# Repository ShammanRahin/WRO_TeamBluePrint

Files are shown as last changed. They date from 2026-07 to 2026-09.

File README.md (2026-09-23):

# Team Blueprint — WRO Future Engineers 2026

<p align="center">
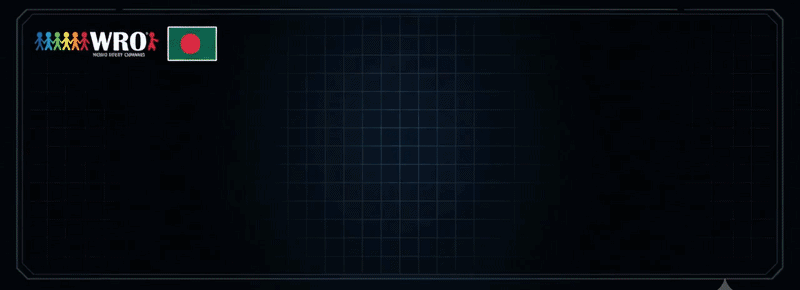
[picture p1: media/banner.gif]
Team Blueprint - WRO Future Engineers 2026
  
</p>

<div align="center">

### National Champions — WRO Bangladesh 2026, Future Engineers
### Heading to the WRO Open Championship Asia Pacific · Hyderabad, India · 25–27 September 2026








**[The Team](#1-the-team)** · **[The Vehicle](#3-the-vehicle)** · **[System Architecture](#4-system-architecture)** · **[How It Thinks](#5-how-the-car-thinks)** · **[Engineering Breakthroughs](#6-key-engineering-findings)** · **[Build & Calibrate](#7-build--fabrication)** · **[Troubleshooting](#9-field-troubleshooting)** · **[Sponsors](#15-sponsors--acknowledgements)**

</div>

---

## Knowledge Index & Deep-Dive Directory

> This repository is structured into an executive master overview below and dedicated technical deep-dive documents. If you want in-depth equations, calibration routines, or build instructions, use the index below:

| System Domain | Master Overview | Full Detailed Technical Guide | Primary Topics & Highlights |
|:---|:---|:---|:---|
| **Autonomous Logic** | [Section 5](#5-how-the-car-thinks) | **[docs/control_architecture.md](docs/control_architecture.md)** | State machines, lane-gap odometry correction, heading hold, 6-phase obstacle FSM, Pi perception |
| **Research & Findings** | [Section 6](#6-key-engineering-findings) | **[docs/engineering_findings.md](docs/engineering_findings.md)** | Optical slot collimators, mathematical parking failure proof, 3 steering geometries compared |
| **Mechanical & Build** | [Section 7](#7-build--fabrication) | **[docs/build_guide.md](docs/build_guide.md)** | 3D printing parameters, Dhaka-milled isolation PCBs, avionics wiring, step-by-step assembly |
| **Sensor Calibration** | [Section 8](#8-sensor-calibration) | **[docs/calibration.md](docs/calibration.md)** | 8-step empirical calibration protocol, regression math, slew limiters, master constants table |
| **Diagnostics & Pit Fixes** | [Section 9](#9-field-troubleshooting) | **[docs/troubleshooting.md](docs/troubleshooting.md)** | 10 real-world failure modes, root-cause analyses, and verified competition fixes |
| **Engineering Chronicle** | [Section 10](#10-engineering-chronicle) | **[docs/timeline.md](docs/timeline.md)** | Dated build log from July 2026 to present, Asia Pacific Championship rebuild notes |
| **Electrical Design** | [Section 4](#4-system-architecture) | **[electrical/ELECTRICAL.md](electrical/ELECTRICAL.md)** | Power domains, star ground, bus architecture, harness standard |
| **Hardware Specifications** | [Section 3](#3-the-vehicle) | **[SPECSHEET.md](SPECSHEET.md)** | As-built geometry, rule constraints, and the dated design record behind them |
| **Architectural Decisions** | — | **[DECISIONS.md](DECISIONS.md)** | 29 dated Architecture Decision Records (ADRs) with trade-offs and supersessions |
| **Bill of Materials** | — | **[BOM.md](BOM.md)** | Component list, status, and mass budget |

---

## 1. The Team

> **Three students. Three universities. One autonomous car brought to life over 2 AM calls and assembled wherever there was a working soldering iron.**

We are from **IUT**, **MIST**, and **NUB** — three engineering universities scattered across Bangladesh. Because of the distance between campuses, our vehicle was engineered through late-night collaborative design sessions, simulations, and weekend build sessions wherever the three of us could meet.

* **National Champions**: 1st Place at WRO Bangladesh 2026 National Final (*Future Engineers*).
* **International Finalists**: Representing Bangladesh at the WRO Open Championship Asia Pacific in Hyderabad, India (September 25–27, 2026).
* **Core Philosophy — Evidence over Vibes**: We try not to guess. Key design choices (steering geometry, gear ratio, sensor mounting, parking strategy) were simulated in Python or measured on the mat, and the dated record of each decision — including the ones the build later overturned — is kept in [`DECISIONS.md`](DECISIONS.md).

<table align="center">
<tr>
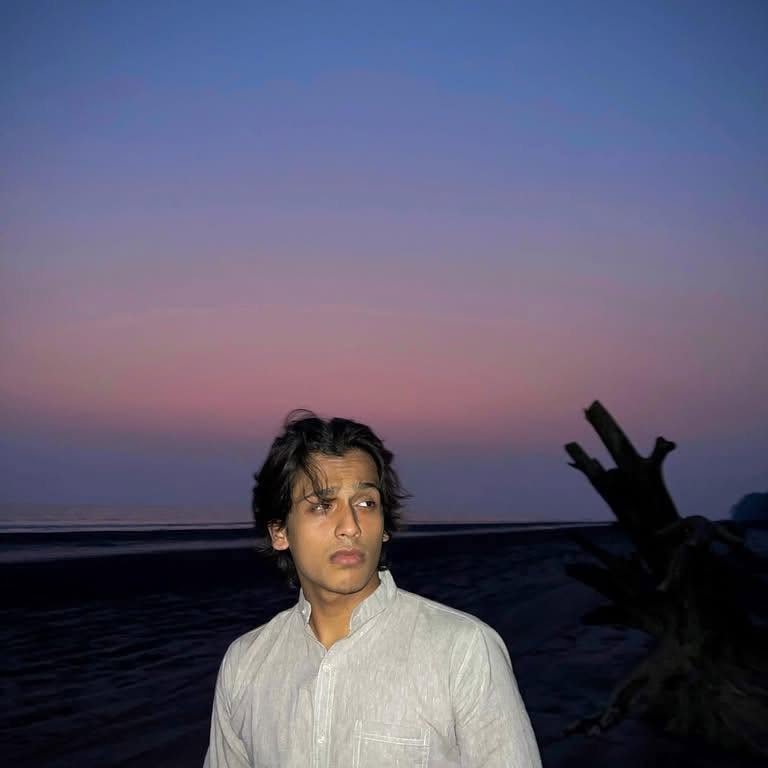
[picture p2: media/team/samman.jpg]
Samman Rahin Shanto
<td align="center" width="33%"></td>
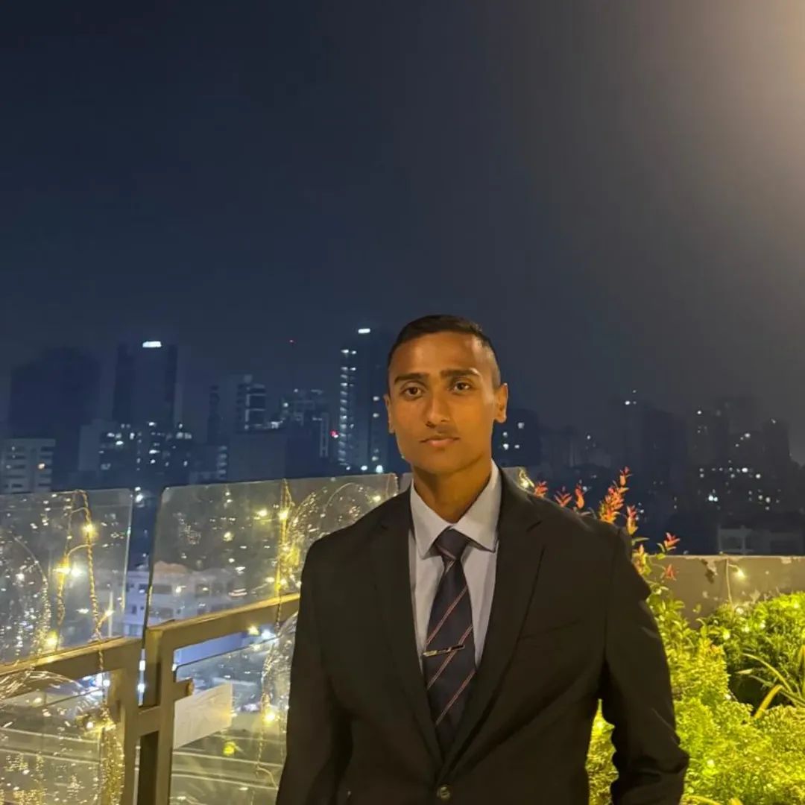
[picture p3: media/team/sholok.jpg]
Syed Subeh-Sadik Sholok
<td align="center" width="33%"></td>
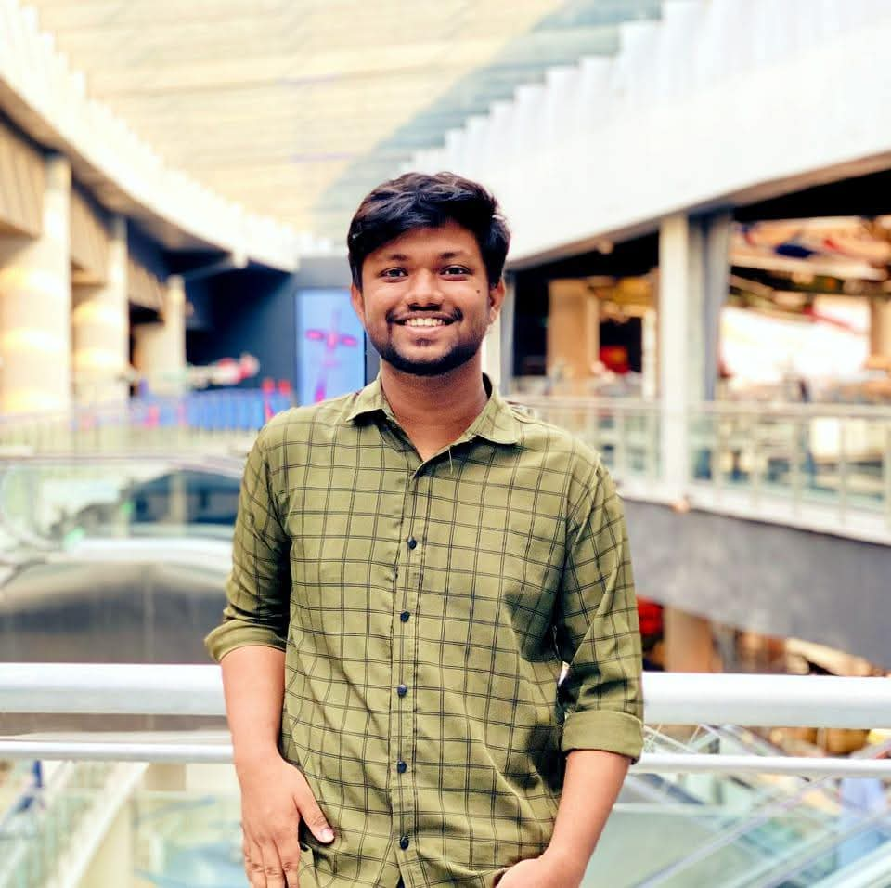
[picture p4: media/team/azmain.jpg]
MD. Azmain Sheikh Rubayed
<td align="center" width="33%"></td>
</tr>
<tr>
<td align="center"><b>Samman Rahin Shanto</b><br/><sub>Team Lead &amp; Electrical</sub></td>
<td align="center"><b>Syed Subeh-Sadik Sholok</b><br/><sub>Firmware &amp; Control</sub></td>
<td align="center"><b>MD. Azmain Sheikh Rubayed</b><br/><sub>CAD &amp; Fabrication</sub></td>
</tr>
<tr>
<td align="center"><sub>Islamic University of Technology (IUT)</sub></td>
<td align="center"><sub>Military Institute of Science &amp; Technology (MIST)</sub></td>
<td align="center"><sub>Northern University Bangladesh (NUB)</sub></td>
</tr>
<tr>
<td align="center"><sub>Power architecture, PCB layout, and noise-isolated star-ground power rails.</sub></td>
<td align="center"><sub>Low-level real-time FSM, gyro-terminated turns, and obstacle evasion algorithms.</sub></td>
<td align="center"><sub>Fusion 360 design, 3D printing, and Dhaka-milled PCB fabrication.</sub></td>
</tr>
<tr>
<td align="center"><sub><a href="mailto:sammanrahin.iut@gmail.com">sammanrahin.iut@gmail.com</a></sub></td>
<td align="center"><sub><a href="mailto:syedsholok.mist@gmail.com">syedsholok.mist@gmail.com</a></sub></td>
<td align="center"><sub><a href="mailto:azmiansheikh.nub@gmail.com">azmiansheikh.nub@gmail.com</a></sub></td>
</tr>
</table>

<details>
<summary><b>View our 2-year background across 35+ national robotics competitions</b></summary>
<br>

Before WRO, our members competed across 35+ national robotics events in Bangladesh (line followers, robo sumo, robo soccer, and battlebots). This background formed our engineering habits: rapid prototyping, in-house PCB milling, and vibration-proof avionics wiring.

| Year | Event | Segment | Result |
|:---:|:---|:---|:---:|
| 2026 | CYBERNAUTS · North South University | Robo Sumo | **Champion** |
| 2026 | IGNITION · KUET | Line Follower | **1st Runner-up** |
| 2025 | Accelerate · IEEE RAS, IUT | Line Follower | **Podium** |
| 2025 | IUT Techathon | Line Follower | **Champion** |
| 2024 | Traction · BRAC University | Pathfinder / LFR | **2nd Runner-up** |

<p align="center">
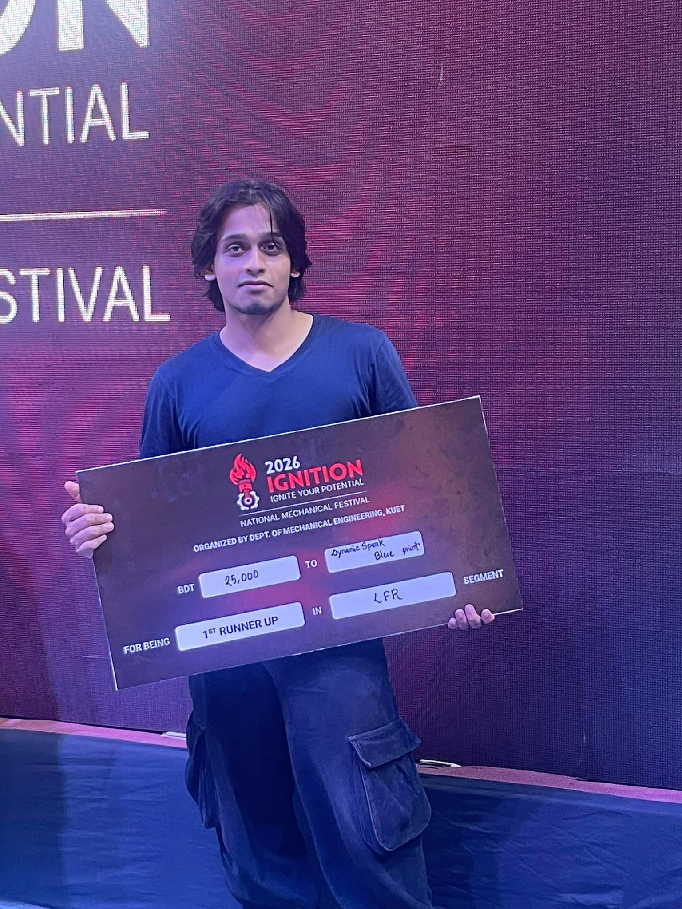
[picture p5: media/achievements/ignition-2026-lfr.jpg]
IGNITION 2026 KUET
  
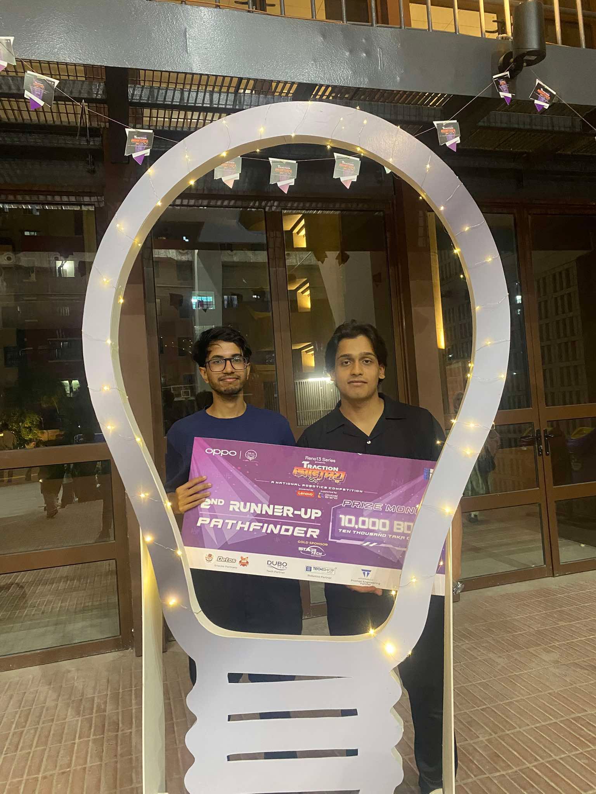
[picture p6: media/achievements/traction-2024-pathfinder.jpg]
Traction 2024 BRAC
  
</p>

</details>

---

## 2. The Challenge

Autonomous miniature racing in the WRO Future Engineers category requires solving coupled real-time robotic problems under strict physical constraints:
* **Optical Noise**: High-reflectance white vinyl mats against low-reflectance matte black walls produce severe infrared crosstalk for distance sensors.
* **Randomized Racing Direction**: Track direction (clockwise vs. counter-clockwise) is drawn randomly before each round and must be detected dynamically.
* **Dynamic Obstacle Avoidance**: Detecting and evading randomized traffic pillars (green = pass left, red = pass right) at speed while preserving track boundaries.
* **Micro-Bay Parking**: Maneuvering into a bay only $1.5 \times$ the vehicle's length ($275.25\text{ mm}$ for our $183.5\text{ mm}$ chassis baseplate / $411.4\text{ mm}$ total envelope) without touching boundary limiters.

---

## 3. The Vehicle

### 3D CAD Digital Twin & Interactive Assembly

> **Interactive 3D on GitHub**: GitHub natively supports interactive WebGL 3D rendering. **Click the rotating assembly below** or open [`models/ASMB.stl`](models/ASMB.stl) to rotate, zoom, and inspect the physical robot assembly directly in your browser. Complete engineering assemblies are provided in [`models/ASMB.3mf`](models/ASMB.3mf) (native multi-material) and [`models/ASMB.step`](models/ASMB.step) (parametric CAD).

<p align="center">
  <a href="models/ASMB.stl" title="Click to open interactive 3D WebGL viewer on GitHub">
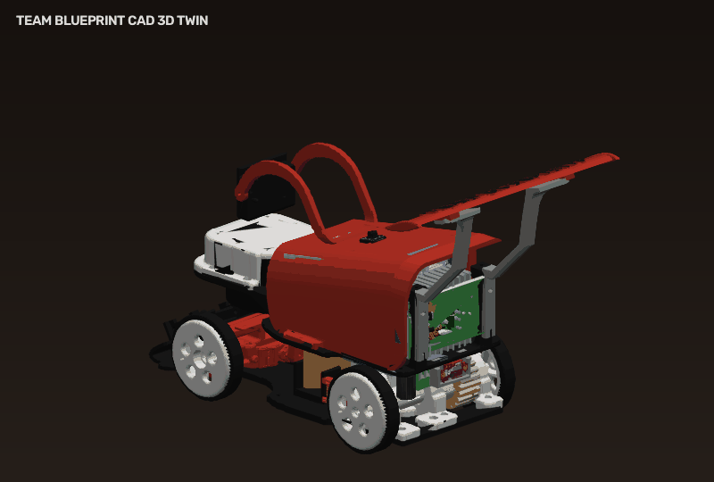
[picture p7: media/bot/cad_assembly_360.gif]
Team Blueprint WRO 2026 Autonomous Vehicle - 3D CAD Assembly
    
  </a>
</p>

<p align="center">
  
  
  
  
</p>

### Vehicle Photographs (6 Required Perspectives)

> Captured in full competition configuration with 3D-printed red chassis, obstacle round camera mast, and dual-tier compute platform. High-resolution source images are located in [`v-photos/`](v-photos/README.md).

<table align="center">
  <tr>
    <th align="center">Front View</th>
    <th align="center">Top View</th>
    <th align="center">Back View</th>
  </tr>
  <tr>
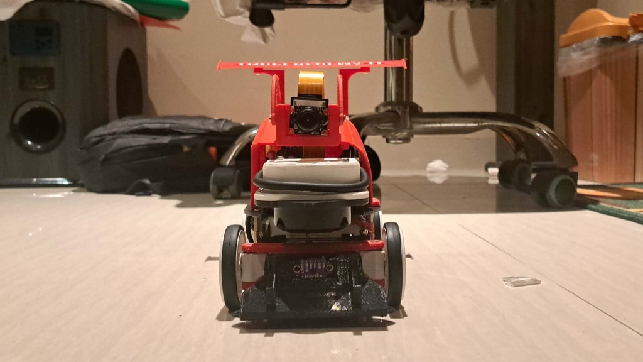
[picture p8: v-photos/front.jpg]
Front View
    <td align="center" width="33%"><br/><sub><b>Front</b>: Fisheye camera mount &amp; bumper</sub></td>
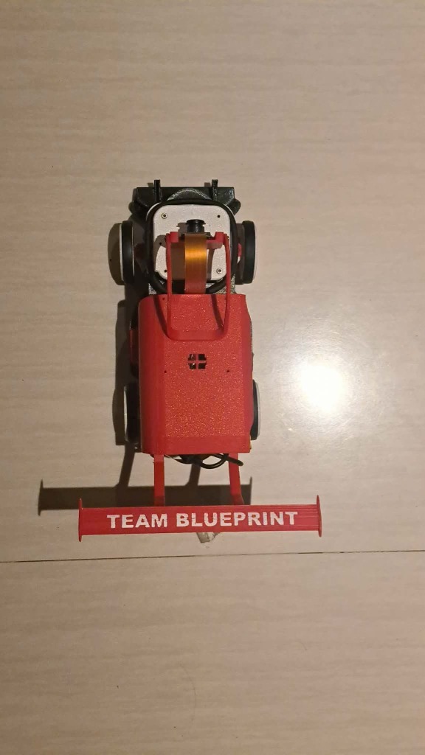
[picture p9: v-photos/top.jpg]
Top View
    <td align="center" width="33%"><br/><sub><b>Top</b>: Chassis layout &amp; rear wing</sub></td>
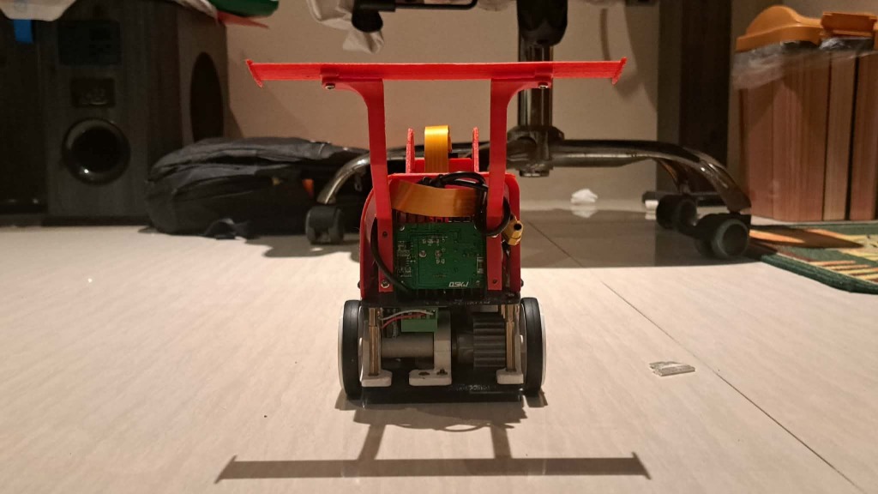
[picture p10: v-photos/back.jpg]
Back View
    <td align="center" width="33%"><br/><sub><b>Back</b>: Power regulator PCB &amp; drive axle</sub></td>
  </tr>
  <tr>
    <th align="center">Left Side View</th>
    <th align="center">Right Side View</th>
    <th align="center">Bottom View</th>
  </tr>
  <tr>
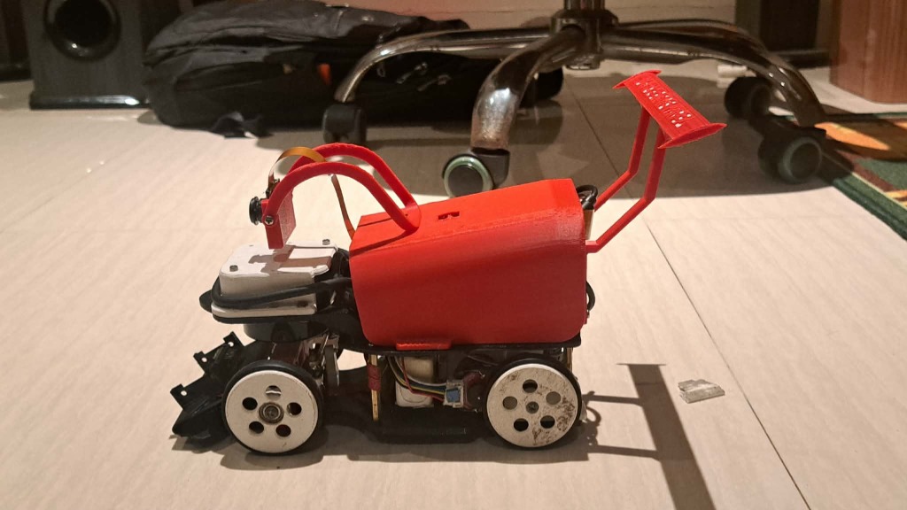
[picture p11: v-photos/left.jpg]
Left Side View
    <td align="center" width="33%"><br/><sub><b>Left</b>: Profile &amp; Ackermann steering</sub></td>
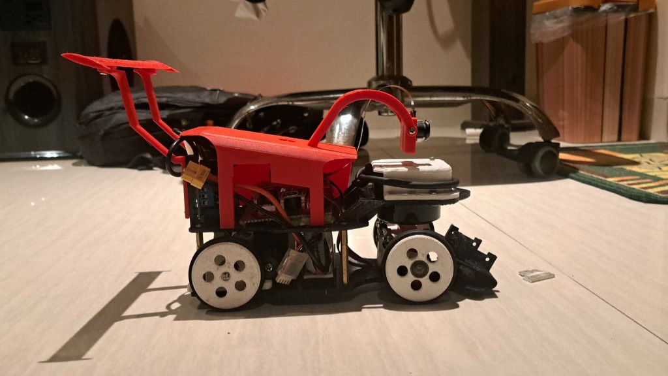
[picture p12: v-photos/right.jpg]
Right Side View
    <td align="center" width="33%"><br/><sub><b>Right</b>: Wiring harness &amp; wheel hubs</sub></td>
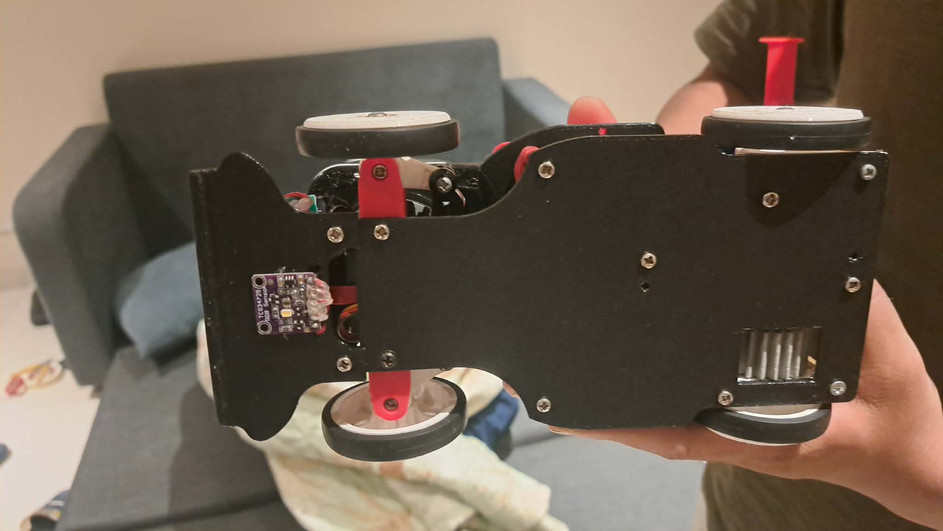
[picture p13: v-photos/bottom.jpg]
Bottom View
    <td align="center" width="33%"><br/><sub><b>Bottom</b>: TCS34725 floor sensor &amp; underbody</sub></td>
  </tr>
</table>

### Bill of Materials & Hardware Components

> Below is the complete as-built hardware bill of materials for Team Blueprint, including actual component photographs, functional subsystem assignments, international supplier links, and local Bangladesh supplier links with current market prices. See [`BOM.md`](BOM.md) for full power/mass budgets.

| Photo | Component & Specification | Subsystem / Role | International Link & Price | Local Link (BD) & Price |
|:---:|:---|:---|:---:|:---:|
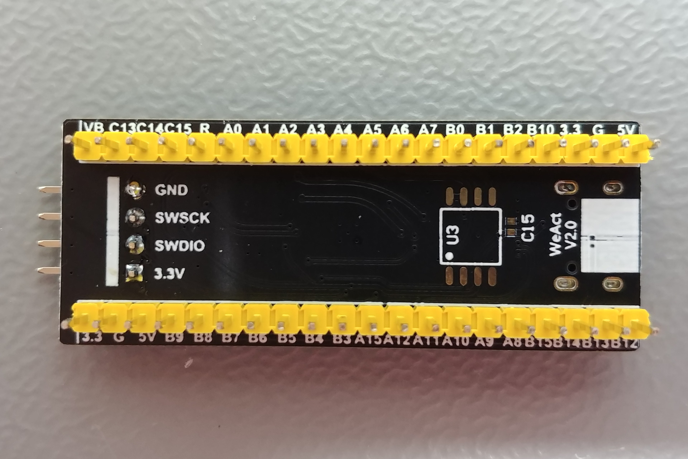
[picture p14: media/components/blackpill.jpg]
STM32F411CEU6 Black Pill
|  | **STM32F411CEU6 "Black Pill"**<br/>ARM Cortex-M4 @ 100 MHz, 512 KB Flash, 128 KB SRAM | Main Real-time Microcontroller (Firmware & Low-Level Control) | [WeAct Studio / AliExpress](https://www.aliexpress.com/item/1005001456186625.html)<br/>**~$3.80** | [RoboticsBD](https://www.roboticsbd.com/development-boards/stm32f411ceu6-black-pill-development-board)<br/>**~৳520** |
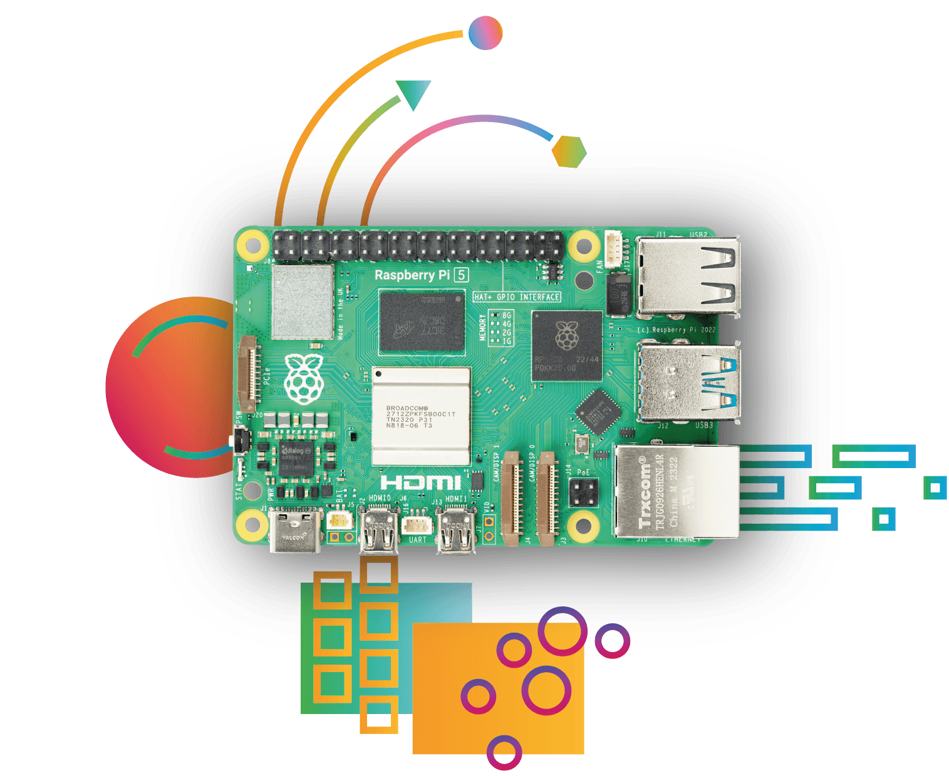
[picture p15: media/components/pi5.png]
Raspberry Pi 5 8GB
|  | **Raspberry Pi 5 (8 GB)**<br/>Broadcom BCM2712 Quad-core ARM Cortex-A76 @ 2.4 GHz | High-Level AI, Vision Processing & LiDAR SLAM Compute | [Raspberry Pi Foundation](https://www.raspberrypi.com/products/raspberry-pi-5/) / [DigiKey](https://www.digikey.com/en/products/detail/raspberry-pi/SC1112/21657805)<br/>**~$80.00** | [RoboticsBD](https://www.roboticsbd.com/single-board-computers/raspberry-pi-5-8gb)<br/>**~৳12,500** |
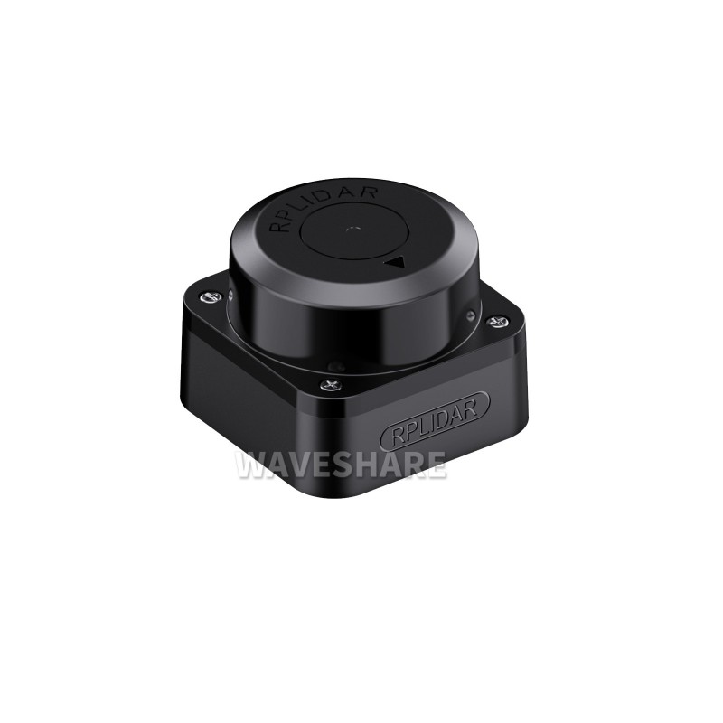
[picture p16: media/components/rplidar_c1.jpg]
Slamtec RPLIDAR C1
|  | **Slamtec RPLIDAR C1**<br/>360° DTOF Laser Scanner, 12 m range, 5 kHz sample rate | 2D LiDAR Localization & Obstacle Boundary Mapping | [Slamtec](https://www.slamtec.com/en/Lidar/C1) / [RobotShop](https://www.robotshop.com/products/slamtec-rplidar-c1-360-degree-laser-range-scanner)<br/>**~$89.00** | [RoboticsBD](https://www.roboticsbd.com/sensors/slamtec-rplidar-c1)<br/>**~৳13,500** |
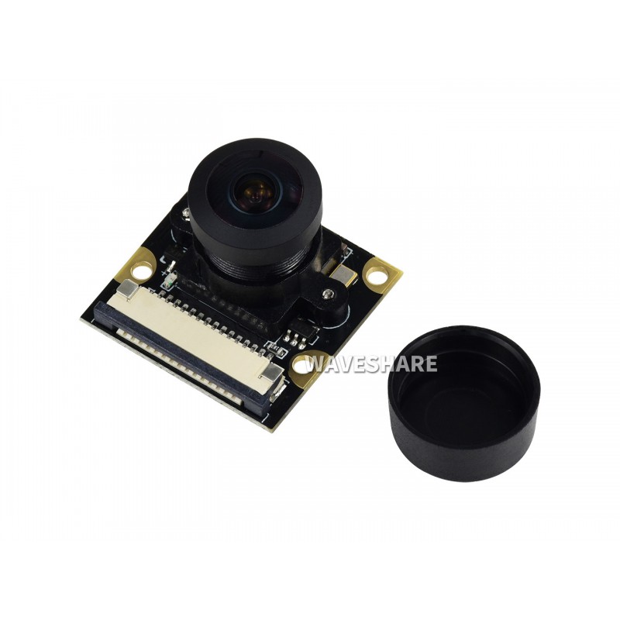
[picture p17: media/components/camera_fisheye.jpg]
160° Fisheye Camera Module
|  | **160° Ultra-Wide Fisheye Camera**<br/>OV5647 5 MP, low-distortion panoramic optics | Color Computer Vision (Red / Green Pillar Tracking) | [Waveshare](https://www.waveshare.com/rpi-camera-g.htm) / [AliExpress](https://www.aliexpress.com/item/32819894065.html)<br/>**~$11.50** | [RoboticsBD](https://www.roboticsbd.com/camera-modules/raspberry-pi-fisheye-camera-160-fov)<br/>**~৳1,650** |
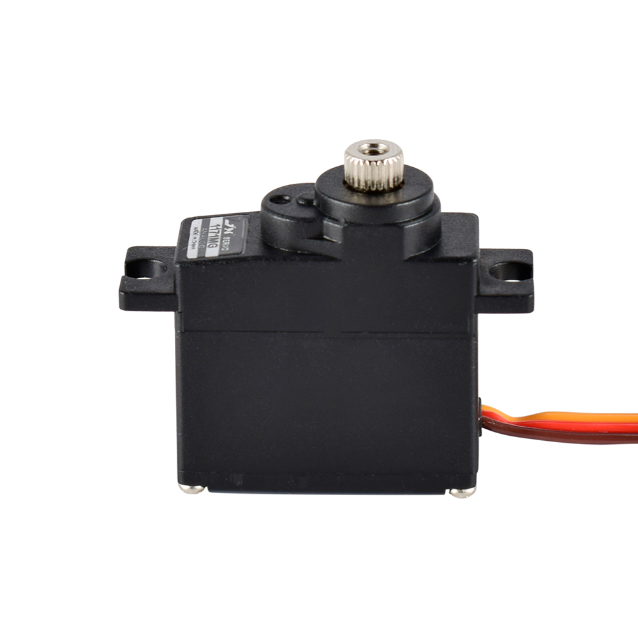
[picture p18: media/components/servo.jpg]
JX PS-1171MG Digital Servo
|  | **JX PS-1171MG Digital Servo**<br/>17 g, metal-gear, 3.5 kg·cm torque @ 6 V, 0.11 s/60° | Ackermann Kinematic Steering ($\pm 35^\circ$ travel) | [Banggood](https://www.banggood.com/JX-PDI-1171MG-17g-3_5kg-Metal-Gear-Digital-Core-Servo-p-1075163.html) / [AliExpress](https://www.aliexpress.com/item/32798939228.html)<br/>**~$7.20** | [RoboticsBD](https://www.roboticsbd.com/motors-servos/jx-servo-ps-1171mg-metal-gear-digital-servo)<br/>**~৳950** |
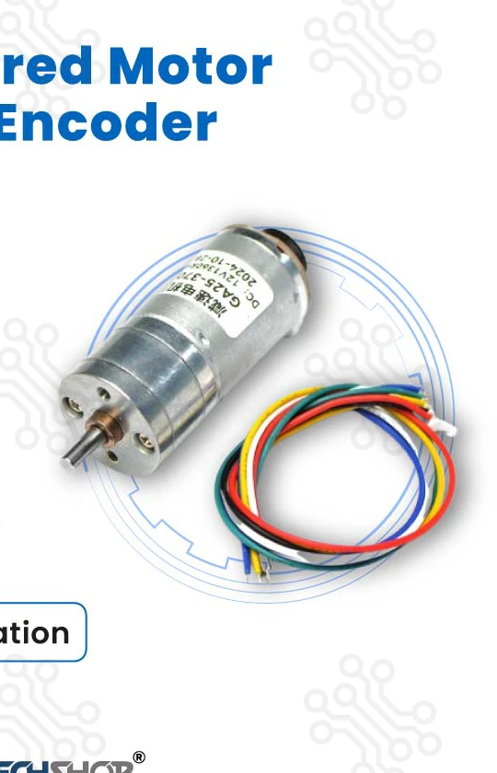
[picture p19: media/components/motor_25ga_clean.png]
25GA-370 12V DC Gearmotor
|  | **25GA-370 12V DC Gearmotor**<br/>1331 RPM motor, integrated magnetic Hall encoder | Primary Traction Powertrain (5:1 external reduction) | [Pololu / AliExpress](https://www.aliexpress.com/item/32854341951.html)<br/>**~$10.50** | [RoboticsBD](https://www.roboticsbd.com/motors-servos/25ga-370-12v-dc-gearmotor-with-encoder)<br/>**~৳1,250** |
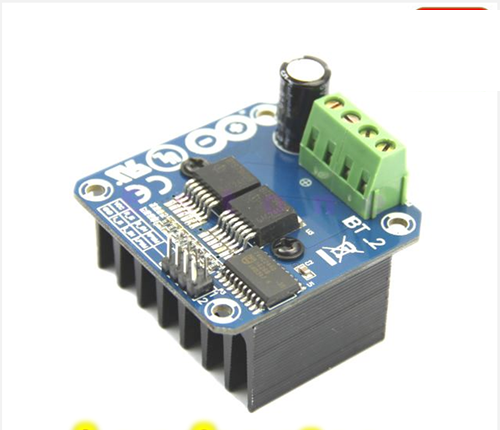
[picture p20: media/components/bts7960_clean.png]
BTS7960 43A Motor Driver
|  | **BTS7960 43A High-Power Driver**<br/>Dual Infineon half-bridge, PWM forward/reverse/brake | Motor Power Drive & Regenerative Braking | [Amazon](https://www.amazon.com/dp/B07TFB22H5) / [AliExpress](https://www.aliexpress.com/item/1005001621844976.html)<br/>**~$4.80** | [TechshopBD](https://techshopbd.com/detail/1820/BTS7960-43A-Motor-Driver)<br/>**~৳620** |
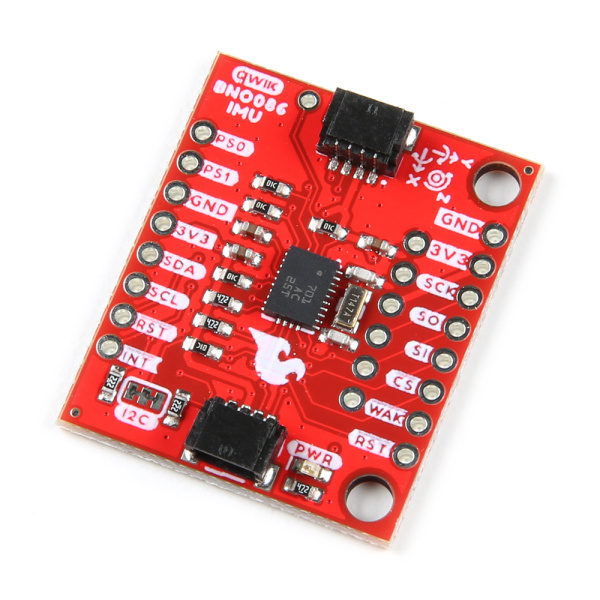
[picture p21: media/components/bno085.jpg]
BNO085 9-DOF IMU
|  | **BNO085 9-DOF IMU Module**<br/>ARM Cortex-M0+ sensor hub, SH-2 Kalman fusion, SPI | Absolute Heading, Drift-Free Yaw & Race Odometry | [Adafruit](https://www.adafruit.com/product/4754) / [SparkFun](https://www.sparkfun.com/products/16974)<br/>**~$19.95** | [RoboticsBD](https://www.roboticsbd.com/sensors/bno085-9-dof-imu-sensor-module)<br/>**~৳2,850** |
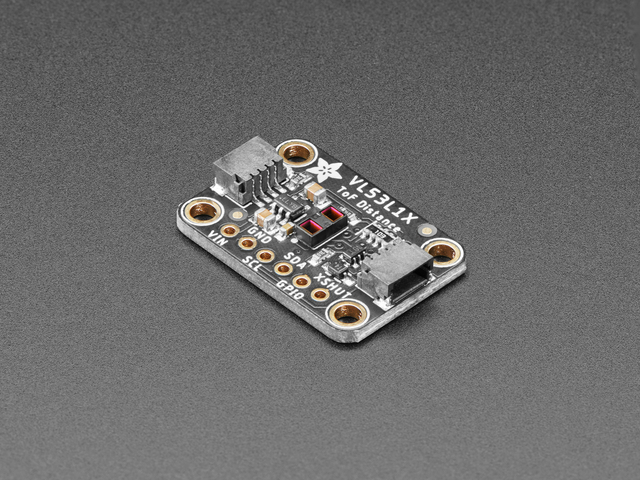
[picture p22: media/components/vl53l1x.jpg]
ST VL53L1X / VL53L0X ToF Sensors
|  | **STMicroelectronics VL53L1X / VL53L0X**<br/>940 nm FlightSense VCSEL ToF, collimated snout | Wall Distance Ranging & Parking Bay Detection | [Pololu](https://www.pololu.com/product/3415) / [Adafruit](https://www.adafruit.com/product/3967)<br/>**~$4.50 ea.** | [RoboticsBD](https://www.roboticsbd.com/sensors/vl53l1x-time-of-flight-distance-sensor)<br/>**~৳520 ea.** |
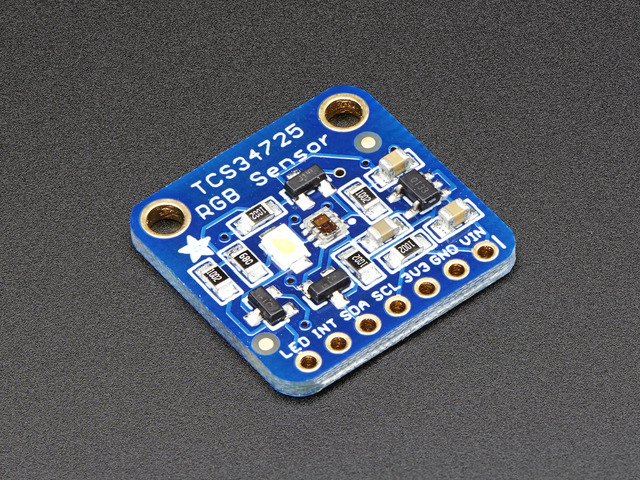
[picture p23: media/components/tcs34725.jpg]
TCS34725 RGB Color Sensor
|  | **TCS34725 RGB Color Sensor**<br/>Integrated IR blocking filter, I²C interface @ 0x29 | Floor Line Detection & Orange Lap Counter | [Adafruit](https://www.adafruit.com/product/1334) / [AliExpress](https://www.aliexpress.com/item/32832813583.html)<br/>**~$4.20** | [RoboticsBD](https://www.roboticsbd.com/sensors/tcs34725-rgb-color-sensor-module)<br/>**~৳480** |
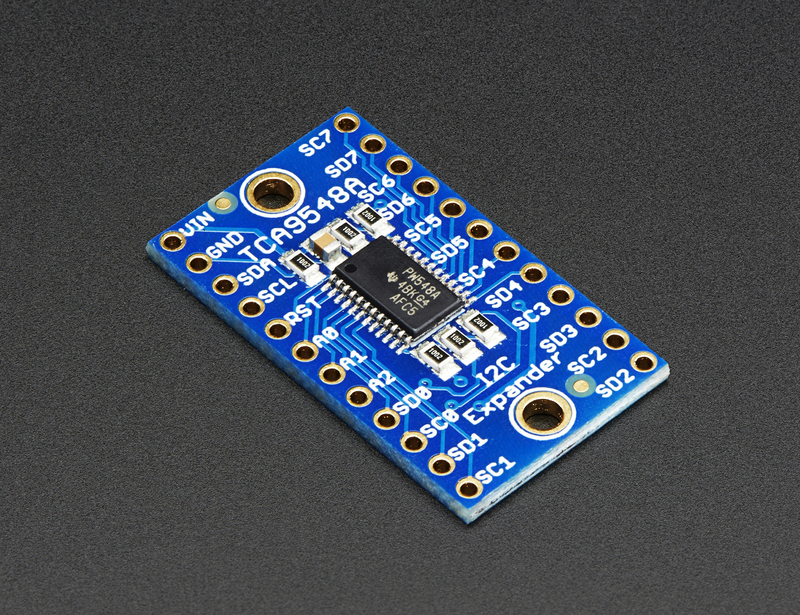
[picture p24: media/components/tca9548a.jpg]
TCA9548A / PCA9548A I2C Mux
|  | **TCA9548A / PCA9548A I²C Multiplexer**<br/>8-channel bidirectional translation, address 0x70 | Multi-Sensor Bus Arbitrator (Prevents Address Collisions) | [Adafruit](https://www.adafruit.com/product/2701) / [AliExpress](https://www.aliexpress.com/item/32831201726.html)<br/>**~$2.20** | [TechshopBD](https://techshopbd.com/detail/2984/TCA9548A-I2C-Multiplexer)<br/>**~৳280** |
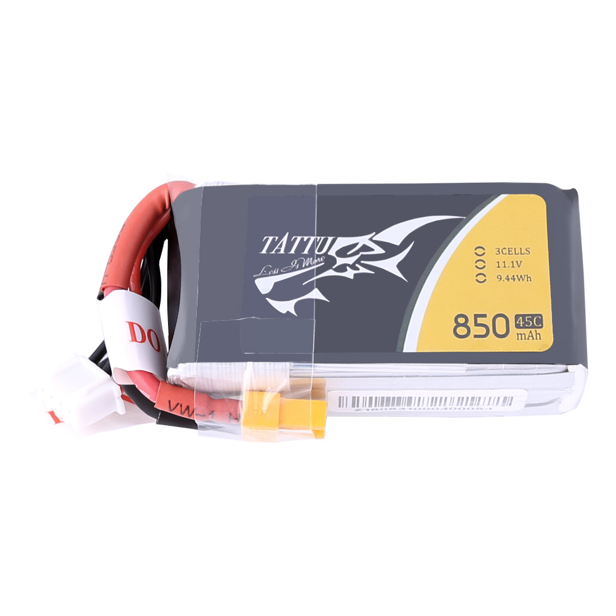
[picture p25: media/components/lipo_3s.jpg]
3S 11.1V LiPo Battery
|  | **3S 11.1V 75C LiPo Battery**<br/>High-discharge lithium-polymer pack with XT30/XT60 | Main Vehicle Traction & Regulated Electronics Power | [HobbyKing](https://hobbyking.com/) / [AliExpress](https://www.aliexpress.com/)<br/>**~$14.00** | [RoboticsBD](https://www.roboticsbd.com/batteries-chargers/3s-lipo-battery-pack)<br/>**~৳1,850** |

### As-Built System Specifications

> **Two firmware generations are in this repository.** The Open Challenge program ([`src/open_round/OpenRound.cpp`](src/open_round/OpenRound.cpp), last changed 2026-09-17) runs on the re-pinned carrier board with a single front VL53L0X. The Obstacle Challenge program ([`src/obstacle_round/ObstacleRound.cpp`](src/obstacle_round/ObstacleRound.cpp)) and the calibration sketches still use the earlier pin map and three VL53L1X sensors. Where the two differ, both values are given below. See [Pin maps](#pin-maps) for details.

| Category | Parameter | Measured / Engineered Value | WRO Limit | Technical Design Notes |
|:---|:---|:---:|:---:|:---|
| **Footprint** | Scored Dimensions | **274.29 × 114.09 mm** (Full) / **183.5 × 101.7 mm** (Base) | $\le 300 \times 200\text{ mm}$ | Fully rule-compliant with 25.7 mm length & 85.9 mm width safety margins |
| | Vehicle Height | **169.19 mm** (To spoiler) / **104.6 mm** (Mid-deck) | $\le 300\text{ mm}$ | Well below the 300 mm rule ceiling; modular perception mast |
| | Total Mass | **~420 g** (Open) / **~540–580 g** (Obstacle, estimated) | $\le 1500\text{ g}$ | See mass budget in [`BOM.md`](BOM.md) |
| **Kinematics** | Wheelbase ($L$) | **136.07 mm** | — | Measured in CAD (136.07 mm axle-to-axle); $R = 194.3\text{ mm}$ |
| | Track Width ($W$) | **102.09 mm** (Front centre) / **114.09 mm** (Extreme) | — | Rear track: 84.84 mm centre / 113.59 mm extreme |
| | Steering Mechanism | **Ackermann linkage** | 1 actuator | $107.0^\circ / 73.0^\circ$ arms ($17.0^\circ$) aimed at the rear axle centre |
| | Steering Lock Range | **$\pm 35^\circ$** at knuckles | — | Actuated by JX PS-1171MG digital metal-gear servo |
| | Minimum Turn Radius | **194.3 mm** ($L / \tan 35^\circ$) | — | Well inside the $1000\text{ mm}$ track corridor |
| | Ground Clearance | **6.02 mm** | — | Measured from ground contact plane to lowest chassis baseplate point |
| **Powertrain** | Drive Motor | **25GA-370 DC Gearmotor** (12V) | 1 motor | One drive motor, rule-compliant |
| | Gear Reduction | **5:1 Spur Gear Drive** | — | Theoretical top speed $0.70\text{ m/s}$ |
| | Drive Axle | **Solid Steel Rear Axle** (No differential) | 1 driven axle | Unbiased straight odometry; no diff backlash |
| | Odometry Scale | **14.853 ticks/cm** (Open fw) / **31.933 ticks/cm** (Obstacle fw) | — | 0.67 mm / 0.31 mm per count; hardware quadrature on an STM32 timer |
| **Sensing** | Inertial Measurement| **BNO085 (SPI)** | — | Game-rotation-vector yaw at ~100 Hz |
| | Distance | **1× VL53L0X front** (Open fw) / **3× VL53L1X L, R, F** (Obstacle fw) | — | Behind a TCA9548A mux; 3D-printed slot collimators |
| | Floor Color | **TCS34725 RGB Color Sensor** | — | Downward-facing with light hood |
| | 2D LiDAR Scanner | **Slamtec RPLIDAR C1 (360° DTOF)** | — | Obstacle round only, USB to the Pi |
| | Optical Camera | **160° FoV Fisheye Lens** | — | Pillar colour and bearing (Obstacle round) |
| **Compute** | Real-Time Master | **STM32F411CEU6 (Black Pill)** | — | ARM Cortex-M4 @ 100 MHz, cooperative non-blocking loop |
| | High-Level Vision | **Raspberry Pi 5 (8GB)** | — | Camera + LiDAR threads (Obstacle round only) |

### WRO Rule Compliance
* **Actuators**: Exactly one motor driving a single solid rear axle; exactly one steering servo.
* **RF & Wireless (Rule 11.10)**: Wi-Fi and Bluetooth disabled via `dtoverlay=disable-wifi` / `dtoverlay=disable-bt` in `/boot/firmware/config.txt` on the Raspberry Pi 5. The Pi is physically unplugged for the Open round.
* **Control Interfaces (Rules 9.10, 9.11)**: One master switch for power; a separate momentary start button.
  > ⚠️ **Open item:** the current Open round firmware does **not** read a start button yet — it starts after a fixed 5 s countdown (`START_DELAY_MS`, `BTN_START_PIN = PB15` is marked "not wired yet"). Rule 9.11 requires a start button, so this must be wired and enabled before competition. The Obstacle round firmware already waits for the button on PA5.
* **Vehicle & Team Visuals**:
  * Vehicle photos from all 6 angles: [Section 3](#vehicle-photographs-6-required-perspectives) and [`v-photos/`](v-photos/README.md)
  * Official and informal team photos: [`t-photos/`](t-photos/README.md) *(still to be added)*
  * Driving demonstration videos: [`video/video.md`](video/video.md)

---

## 4. System Architecture

The robot uses a **two-tier compute hierarchy**:

```mermaid
graph TD
    subgraph Power ["Power Subsystem (Single Star Ground)"]
        BAT["3S LiPo Battery (11.1V)"] --> REG6["6.0V 3A Buck (Servo only)"]
        BAT --> REG5["5.0V 2A Buck (STM32 & Sensors)"]
        BAT --> REG55["5.1V 5A Buck (Pi 5 + RPLIDAR C1)"]
        BAT --> DRV_PWR["Direct Battery Rail (BTS7960 H-Bridge)"]
    end

    subgraph LowLevel ["Real-Time Control Tier (STM32F411CEU6 @ 100MHz)"]
        STM["STM32 State Machine"]
        IMU["BNO085 IMU (SPI, ~100 Hz yaw)"] -->|Heading| STM
        ENC["Motor Quadrature Encoder"] -->|Hardware timer| STM
        BTN["Start Button"] -->|GPIO| STM
        MUX["TCA9548A I2C Mux (0x70)"] <-->|I2C 400kHz| STM
        MUX --> TOF["VL53L0X / VL53L1X ToF (Collimated)"]
        MUX --> COL["TCS34725 Floor RGB"]

        STM -->|PWM, slew-limited| SERVO["JX PS-1171MG Servo"]
        STM -->|RPWM / LPWM| BTS["BTS7960 Driver"] --> MOTOR["25GA Drive Motor"]
    end

    subgraph HighLevel ["High-Level Perception Tier (Obstacle Round Only)"]
        PI["Raspberry Pi 5 (8GB)"]
        LIDAR["Slamtec RPLIDAR C1 (360° DTOF)"] -->|USB Serial| PI
        CAM["160° Fisheye Camera"] -->|CSI| PI
        PI -->|"UART 115200, ASCII V-frames"| STM
    end

    style Power fill:#fff3e0,stroke:#f57c00,stroke-width:1.5px
    style LowLevel fill:#e3f2fd,stroke:#1976d2,stroke-width:1.5px
    style HighLevel fill:#fce4ec,stroke:#c2185b,stroke-width:1.5px
```

### Electrical Schematic & Wiring
* Block diagram: [`schemes/wiring_block_diagram.png`](schemes/wiring_block_diagram.png).
  > ⚠️ This diagram is dated **2026-07-26** and predates the I²C multiplexer, the BNO085, the Raspberry Pi 5 and the JX servo. It needs regenerating (`electrical/make_block_diagram.py`) from the pin maps below.
* Power isolation rules, decoupling and harness standards: [`electrical/ELECTRICAL.md`](electrical/ELECTRICAL.md).

### Pin maps

| Function | Current carrier — `OpenRound.cpp` | Earlier map — `ObstacleRound.cpp`, calibration sketches |
|:---|:---|:---|
| Motor (BTS7960) | PA2 RPWM (fwd), PA3 LPWM (rev); EN tied high on board | PB9 RPWM, PB8 LPWM, PB1 EN |
| Servo | PA8 | PA8 |
| Encoder | TIM5 on PA0 / PA1 (32-bit, sign negated in firmware) | TIM3 on PA6 / PA7 |
| IMU (BNO085, SPI) | PA5 SCK, PA6 MISO, PA7 MOSI, PA4 CS, PB0 INT, PB1 RST | PB3 SCK, PB4 MISO, PB5 MOSI, PB0 CS, PB13 INT, PB14 RST |
| I²C to mux | PB6 SCL, PB7 SDA, PB8 mux reset | PB6 SCL, PB7 SDA |
| ToF | VL53L0X front on mux ch 3 | VL53L1X left / right / front on mux ch 1 / 3 / 4 |
| Floor colour | TCS34725 on mux ch 4 | TCS34725, channel auto-detected |
| Start button | PB15 (reserved, **not read yet**) | PA5, active-low |
| Status LEDs | PB12 run, PB13 orange seen, PB14 blue seen | — |

> The obstacle firmware must be ported to the current pin map before it can run on the re-pinned carrier.

### Four Isolated Power Domains
1. **Motor Rail**: Unregulated battery voltage routed directly to the BTS7960 H-bridge. High switching currents bypass the carrier board entirely.
2. **Servo Rail (6.0V, 3A)**: Dedicated buck regulator absorbing servo current spikes, preventing MCU brownout resets.
3. **Logic Rail (5.0V → 3.3V)**: Dedicated buck regulator feeding the STM32 and the sensor board's local 3.3 V regulator.
4. **Perception Rail (5.1V, 5A)**: Separate harness feeding the Raspberry Pi 5 and RPLIDAR C1 (unplugged during the Open round).

---

## 5. How the Car Thinks

> **Deep-Dive Documentation:** For state machine details, control laws and perception thread mechanics, see **[`docs/control_architecture.md`](docs/control_architecture.md)**.

### Core Navigation Invariants
1. **"The heading is the truth. Everything else is a hint."** Wheel slip, floor reflections, and camera noise are common. The IMU yaw decides when a manoeuvre is finished: a $90^\circ$ turn ends when the heading has changed by $90^\circ$ (within `TURN_STOP_DEG` = $0.3^\circ$). Encoder distance is used only as a safety cap in case the IMU never gets there.
2. **Heterogeneous Split**: The STM32 owns all actuators. The Raspberry Pi 5 only sends advisory pillar frames (`V,<colour>,<dx>,<area>`). If no frame arrives for $250\text{ ms}$, the STM32 treats vision as absent and keeps driving on its own navigation.
3. **Corners Come First**: An avoidance manoeuvre is not started once a corner line has armed the turn and the front wall is within `FRONT_TURN_MM`. Missing a pillar loses points; missing a corner ends the run.

```mermaid
stateDiagram-v2
    direction LR
    [*] --> WAIT_START
    WAIT_START --> DRIVE_TO_CORNER : start (button, or 5 s countdown on current Open fw)
    DRIVE_TO_CORNER --> TURNING : corner line armed<br/>AND (front ToF ≤ 700 mm OR side wall gone OR distance backstop)
    DRIVE_TO_CORNER --> AVOID : pillar engaged, no corner imminent (Obstacle round)
    AVOID --> DRIVE_TO_CORNER : manoeuvre complete
    TURNING --> LANE_CORRECT : heading moved 90°
    LANE_CORRECT --> DRIVE_TO_CORNER : shuffle + realign done
    LANE_CORRECT --> FINAL_STRAIGHT : after corner 12
    FINAL_STRAIGHT --> FINISHED : measured distance to start section
    DRIVE_TO_CORNER --> RECOVER : front wall < 200 mm (Open round)
    RECOVER --> DRIVE_TO_CORNER : backed off, resume
    FINISHED --> [*]
```

### Lane-Gap Odometry Correction
To correct lateral drift over 12 corners without relying on wall-following, we use the geometric property that the orange and blue corner lines **fan out radially**:
* The distance travelled between crossing the first line and its partner line indicates the car's lateral position in the lane.
* The gap measured at Corner 1 becomes the reference (`gapRefCm`; the default before it is learned is `GAP_THRESHOLD_CM` = 20 cm).
* At every later corner:
  $$\Delta\text{gap} = \text{measured gap} - \text{reference gap}$$
  $$\theta_{\text{offset}} = \min(4^\circ/\text{cm} \cdot |\Delta\text{gap}|,\  30^\circ)$$
  If $|\Delta\text{gap}|$ is under the 2 cm deadband nothing is done. Otherwise the servo is held $\theta_{\text{offset}}$ off straight for $25\text{ cm}$ after the turn, then the car eases back onto the lane heading.

---

## 6. Key Engineering Findings

> **Deep-Dive Documentation:** For the derivations, simulation code, and CAD comparisons, see **[`docs/engineering_findings.md`](docs/engineering_findings.md)**.

1. **Optical Collimation Against Floor Returns**:
   * *Problem*: The white mat reflected the ToF infrared cone back into the sensor at about $166\text{ mm}$, reporting false walls.
   * *Solution*: 3D-printed $2.5 \times 10 \times 20\text{ mm}$ slot collimator snouts with $+2.0^\circ$ upward wedges ([`electrical/collimator.py`](electrical/collimator.py)). With the as-built $136.14\text{ mm}$ wheelbase (rake $0.84^\circ$) the solver puts the first floor return at **$\approx 947\text{ mm}$** ($870\text{ mm}$ with the earlier $110\text{ mm}$ figure), well beyond the side walls at $442.5\text{ mm}$.
2. **Textbook 2-Arc Parallel Parking Fails**:
   * *Proof*: The rigid-body simulation ([`src/sim/park_feasibility.py`](src/sim/park_feasibility.py)) shows a symmetric two-arc reverse park **collides by $25.6\text{ mm}$** inside a $1.5 \times$ car-length bay at $35^\circ$ lock (run at the July wheelbase of $110\text{ mm}$). Because bay length scales with car length, shrinking the chassis does not help, and the longer CAD wheelbase only makes the turn radius larger.
   * *Solution*: A **multi-point shuffle manoeuvre** closed on IMU heading (planned; not yet in the firmware — the obstacle program currently has no parking phase).
3. **Evolution of Three Steering Geometries**:
   * *Attempt 1 (Centre Turntable Pivot)*: Scrapped; rotating the front beam moved each front tyre fore/aft by $\pm 30.1\text{ mm}$, eating 36% of parking-bay slack.
   * *Attempt 2 (Parallelogram Tie-Bar)*: Fixed the swept envelope, but equal steering angles caused tyre scrub in turns.
   * *Attempt 3 (Ackermann Linkage)*: Steering-arm projections meet at the rear axle centre, so the front wheels roll with minimal scrub.

---

## 7. Build & Fabrication

> **Deep-Dive Documentation:** For printing parameters, PCB layouts, and wiring standards, see **[`docs/build_guide.md`](docs/build_guide.md)**.

* **Additive Manufacturing**: Printed on an **Ender 3 V3 SE** in PLA. Drive gears are printed at **90% infill** to resist tooth shearing; non-structural shells and brackets use low infill to save mass.
* **Locally Milled Single-Sided PCBs**: Upper carrier board ($90 \times 70\text{ mm}$) and lower sensor/multiplexer board, $0.6\text{ mm}$ traces and $0.6\text{ mm}$ clearances ([`electrical/DESIGN_RULES.md`](electrical/DESIGN_RULES.md)).
* **Wiring Standard**:
  * **No DuPont jumper wires and no breadboards** on the vehicle.
  * Harnesses use crimped, latching **JST-XH connectors** with heat-shrink strain relief. High-current motor leads use screw terminals with ferrules.

---

## 8. Sensor Calibration

> **Deep-Dive Documentation:** For step-by-step procedures and the reasoning behind each constant, see **[`docs/calibration.md`](docs/calibration.md)**.

Operational constants come from an 8-step calibration protocol ([`src/tools/calibration/`](src/tools/calibration/)):

```mermaid
flowchart LR
    S1["1 · encoder ticks<br/>per revolution"] --> S2["2 · ticks per<br/>centimetre"]
    S2 --> S4["4 · true straight<br/>servo angle"]
    S4 --> S6["6 · ninety degree<br/>turns"]
    S6 --> S7["7 · heading<br/>correction gain"]
    S3["3 · steering jerk"]:::indep
    S5["5 · ToF floor signal<br/>threshold"]:::indep
    S8["8 · floor colour<br/>thresholds"]:::indep
    classDef indep stroke-dasharray: 5 4
```

### Current System Constants (as committed in the firmware)
| Parameter | Open round (`OpenRound.cpp`) | Obstacle round (`ObstacleRound.cpp`) | Calibration Step |
|:---|:---:|:---:|:---|
| `TICKS_PER_CM` | **14.853** | **31.933** | Step 2 |
| `SERVO_TRUE_STRAIGHT` | **71.0°** | **69.0°** | Step 4 |
| `SERVO_MAX_LEFT` / `RIGHT` | 1.0° / 150.0° | 5.0° / 115.0° | Step 4 |
| `SERVO_SLEW` | 2.5°/cycle | 2.5°/cycle | Step 3 |
| `SIGNAL_MIN_MCPS` | — (VL53L0X path has no signal filter) | 4.0 | Step 5 |
| `TURN_KP` / `TURN_KV` | 2.5 / 3.5 | 2.5 / 3.5 | Step 6 |
| `TURN_STOP_DEG` | 0.3° | 0.3° | Step 6 |
| `HEAD_KP` (`KI` = `KD` = 0) | 2.0 | 2.0 | Step 7 |
| Floor ORANGE | %R > 52 & %B < 18 | %R > 35 & %B < 27 | Step 8 |
| Floor BLUE | %B > 23 & %R < 40 | %B > 36 & %R < 24 | Step 8 |

> The open-round values were re-measured on the re-pinned car in September 2026; the obstacle values are from the earlier build and should be re-checked once that program is ported.

---

## 9. Field Troubleshooting

> **Deep-Dive Documentation:** For failure logs, root causes, and fixes, see **[`docs/troubleshooting.md`](docs/troubleshooting.md)**.

| Symptom | Root Cause | Field Remedy |
|:---|:---|:---|
| **Spurious Wall on Open Mat** | White mat reflection clipping ToF beam | Fit collimator snouts + $+2.0^\circ$ wedge; tune `SIGNAL_MIN_MCPS` (Step 5) |
| **Heading Drifts Across Laps** | Low-grade IMU drift / turn overshoot | Use BNO085 (SPI); calibrate `TURN_KP` and `SERVO_TRUE_STRAIGHT` |
| **Double Turn at Single Corner** | Color sensor sweeping line on exit | Post-corner lockout (`POST_CORNER_LOCKOUT_CM = 50 cm`) |
| **Wrong Turn After Avoidance** | Avoidance started too close to a corner | Don't start avoidance once a corner is armed and the wall is close |
| **Wheel Squeal & Wide Turns** | Equal-angle steering scrub | Ackermann steering geometry |
| **Distance Calibration Drift** | Coupler slipping or mass mismatch | Tighten drive grub screws; calibrate at full competition mass |
| **Phantom Red Obstacles** | Orange line seen as red under arena lights | Re-tune HSV bounds in the dashboard; raise `min_blob_area` |
| **Camera "Device Busy"** | `main.py` and `dashboard.py` both opening the camera | Run one at a time; `robodash.service` declares `Conflicts=robot.service` |
| **MCU Reset on Steering Snap** | Servo current spike pulling down logic rail | Isolate servo on dedicated 6.0V 3A buck regulator |
| **Intermittent Vibration Faults** | DuPont jumper pin friction failure | Crimped, latched JST-XH connectors |
| **Car Nosing Into a Wall** | Front wall inside 200 mm | Open fw backs off automatically (`STATE_RECOVER`), up to 3 tries |

---

## 10. Engineering Chronicle

> **Deep-Dive Documentation:** For the full narrative log and competition preparation notes, see **[`docs/timeline.md`](docs/timeline.md)**, **[`DECISIONS.md`](DECISIONS.md)** and **[`journal/`](journal/)**.

* **July 2026**: Simulations showed textbook 2-arc parallel parking cannot clear the bay; multi-point shuffle adopted as the plan. Centre-pivot steering scrapped because of its $\pm 30.1\text{ mm}$ fore/aft tyre sweep. Collimator snouts designed for the ToF floor problem; two-board single-sided PCB stack with star ground.
* **August 2026**: Non-blocking FSM validated, offset-based pillar avoidance added. **Won the WRO Bangladesh National Championship** (20 August 2026).
* **September 2026 (Asia Pacific rebuild)**: Ackermann steering, BNO085 IMU, JX PS-1171MG servo, Raspberry Pi 5 with RPLIDAR C1. Carrier board re-pinned; open-round firmware moved to the new pin map with a single front VL53L0X, re-calibrated constants and a wall-recovery state (15–17 Sept).

---

## 11. Quick Start & Toolchains

### 1. Python Simulations
```bash
git clone https://github.com/ShammanRahin/WRO_TeamBluePrint.git
cd WRO_TeamBluePrint
pip install numpy matplotlib

# Two-arc parking feasibility (the solver only accepts wheelbases that fit a 165 mm body)
python src/sim/park_feasibility.py --wheelbase 110 --plot

# ToF collimator floor-return solver, at the as-built wheelbase
python electrical/collimator.py --wheelbase 136.14 --plot
```

### 2. STM32 Firmware
There is no PlatformIO project in this repository; the firmware is built with the **Arduino IDE + STM32duino core**:

1. Install the *STM32 MCU based boards* core (STMicroelectronics) and the libraries **SparkFun BNO08x Arduino Library**, **Adafruit TCS34725**, and Pololu **VL53L0X** (open round) or **VL53L1X** (obstacle round).
2. Copy the program into a sketch folder of the same name, e.g. `OpenRound/OpenRound.ino` (the Arduino IDE only opens `.ino` sketches).
3. Board: *Generic STM32F4 series*, Part number: *BlackPill F411CE*, USB support: *CDC (generic Serial)*, Upload method: *STM32CubeProgrammer (DFU)*.
4. Put the Black Pill in DFU mode (hold BOOT0, tap NRST, release BOOT0) and upload.

### 3. Raspberry Pi Perception Stack
```bash
cd src/pi
python3 -m venv --system-site-packages ~/robo-env   # picamera2 comes from apt
source ~/robo-env/bin/activate
pip install -r requirements.txt

python3 main.py        # camera + LiDAR fusion (prints to console for now)
```
See [`src/pi/README.md`](src/pi/README.md) for the dashboard and service setup.

---

## 12. WRO Compliance

Self-audit against the **WRO Future Engineers 2026 General Rules** documentation requirements:

| Rule Requirement | Status | Evidence |
|:---|:---:|:---|
| **Public Repository & License** | **Done** | Public GitHub repo, [LICENSE](LICENSE) (MIT) |
| **English README ≥ 5000 Characters** | **Done** | This file |
| **Complete Source Code** | **Done** | Firmware (`src/open_round/`, `src/obstacle_round/`), perception (`src/pi/`), tools (`src/tools/`) |
| **Engineering Process Log** | **Done** | [`docs/timeline.md`](docs/timeline.md), [`DECISIONS.md`](DECISIONS.md), [`journal/`](journal/) |
| **Electromechanical Schematics** | **Needs update** | [`schemes/`](schemes/) diagram is dated 2026-07-26 — see [Section 4](#4-system-architecture) |
| **Driving Demonstration Videos** | **Done** | YouTube links in [`video/video.md`](video/video.md) |
| **Vehicle Photos (All 6 Sides)** | **Done** | Included in [Section 3](#vehicle-photographs-6-required-perspectives) and [`v-photos/`](v-photos/README.md) |
| **Team Photos (Official & Funny)** | **Missing** | [`t-photos/`](t-photos/README.md) contains only the instructions |
| **CAD Sources & Printable Models** | **Done** | Interactive 3D assembly ([`ASMB.stl`](models/ASMB.stl)), CAD master ([`ASMB.step`](models/ASMB.step)) & STLs in [`models/`](models/README.md) |

---

## 13. Repository Map

```
WRO_TeamBluePrint/
├── README.md                      # Executive master documentation
├── SPECSHEET.md                   # As-built geometry, rule constraints, dated design record
├── DECISIONS.md                   # 29 dated decision records with supersessions
├── BOM.md                         # Bill of Materials and mass budget
├── LICENSE                        # MIT License
│
├── docs/                          # Deep-dive technical documentation
│   ├── control_architecture.md    # State machines, lane-gap correction, perception
│   ├── engineering_findings.md    # Collimator maths, parking proof, steering kinematics
│   ├── build_guide.md             # Printing, PCB fabrication, assembly sequence
│   ├── calibration.md             # 8-step calibration suite
│   ├── troubleshooting.md         # Failure modes, causes, and fixes
│   └── timeline.md                # Dated engineering chronicle
│
├── src/
│   ├── open_round/OpenRound.cpp   # STM32 firmware, Open Challenge
│   ├── obstacle_round/            # STM32 firmware, Obstacle Challenge (+ experimental/)
│   ├── pi/                        # Raspberry Pi 5 perception, LiDAR, camera fusion, dashboard
│   ├── sim/                       # Python steering, parking and layout simulations
│   └── tools/                     # calibration/ sketches + suite, bench/ bring-up sketches
│
├── electrical/                    # Electrical design, PCB design rules, collimator solver
├── schemes/                       # Wiring block diagram
├── models/                        # CAD models and STL files (to be added)
├── journal/                       # Day-by-day engineering log
├── media/                         # Diagrams, team portraits, test figures
├── other/                         # Misc. (WRO template folder)
├── t-photos/                      # Team photos (WRO requirement)
├── v-photos/                      # Vehicle photos from 6 sides (WRO requirement)
└── video/                         # Driving demonstration video links
```

---

## 14. Credits & Licence

### Team Blueprint
* **Samman Rahin Shanto** — Team Lead, Power Architecture & PCB Design *(Islamic University of Technology - IUT)*
* **Syed Subeh-Sadik Sholok** — Embedded Firmware, Kinematics & Control Algorithms *(Military Institute of Science and Technology - MIST)*
* **MD. Azmain Sheikh Rubayed** — CAD Modeling, 3D Printing & Mechanical Fabrication *(Northern University Bangladesh - NUB)*

### Institutional Support
Developed collaboratively across **Islamic University of Technology (IUT)**, **Military Institute of Science and Technology (MIST)**, and **Northern University Bangladesh (NUB)**.

### License
This project is open source and available under the **[MIT License](LICENSE)**.

---

## 15. Sponsors & Acknowledgements

<div align="center">

### Special Thanks to Our Official 3D Printing & Prototyping Sponsor

<br/>

<a href="https://www.facebook.com/profile.php?id=61591245009575" target="_blank" rel="noopener noreferrer">
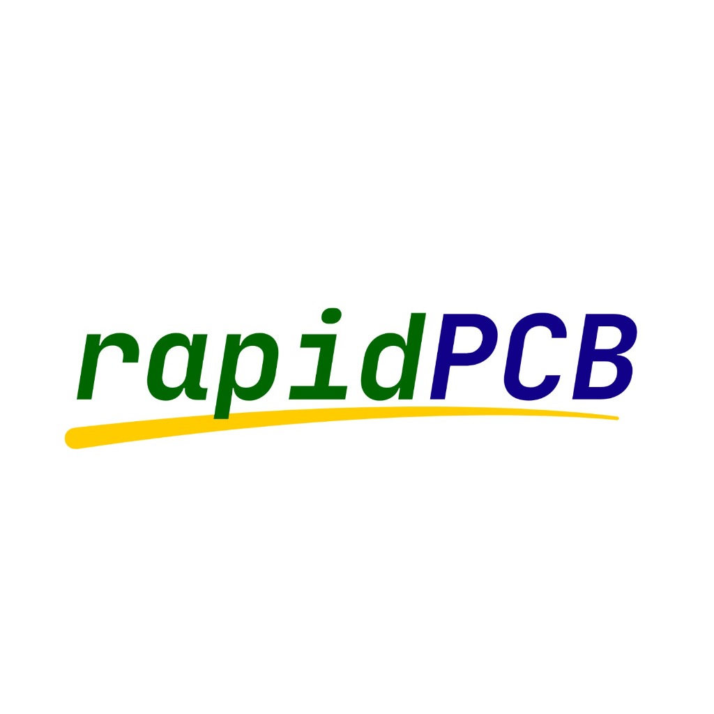
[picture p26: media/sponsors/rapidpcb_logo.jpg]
rapidPCB — Official 3D Printing Sponsor
  
</a>

<br/><br/>

<a href="https://www.facebook.com/profile.php?id=61591245009575" target="_blank" rel="noopener noreferrer">
  
</a>

<br/><br/>

> We extend our deepest gratitude to **[rapidPCB](https://www.facebook.com/profile.php?id=61591245009575)** for generously sponsoring the additive manufacturing and high-precision 3D printing of Team Blueprint’s autonomous racing vehicle. Their rapid fabrication capabilities allowed us to rapidly iterate and produce our lightweight chassis baseplate, avionics mid-deck, Ackermann steering knuckles, sensor mast brackets, and aerodynamic spoiler for the **World Robot Olympiad (WRO) Future Engineers 2026**.

</div>

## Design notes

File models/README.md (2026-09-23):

# models — 3D CAD & Printable Components

Files used to produce the physical parts — 3D-printed and machined/cut pieces for **Team Blueprint** (WRO Future Engineers 2026).

<p align="center">
  <a href="ASMB.stl" title="Click to open interactive 3D WebGL viewer on GitHub">
    Team Blueprint WRO 2026 Autonomous Vehicle - 3D CAD Assembly
  </a>
</p>

<p align="center">
  
  
  
</p>

> **Interactive 3D on GitHub**: GitHub natively renders `.stl` files in 3D! Simply click [`ASMB.stl`](ASMB.stl) in this directory or the button above to rotate, inspect, and pan around the complete robot in your browser without installing any software.

## Available CAD & 3D Printable Models

| Model File | Part / Subsystem | Format | File Size | Description |
|---|---|---|---|---|
| [`ASMB.stl`](ASMB.stl) | Full Assembled Robot (Interactive 3D Preview) | STL (Binary) | ~38.2 MB | Complete assembled vehicle (764k triangles) — **click to view in 3D directly on GitHub** |
| [`ASMB.3mf`](ASMB.3mf) | Complete Multi-Part 3MF Assembly | 3MF (Archive) | ~11.1 MB | Master production print assembly with exact component placements & colors |
| [`ASMB.step`](ASMB.step) | Master CAD Assembly | STEP AP214 | ~64.8 MB | Parametric engineering CAD assembly for Fusion 360 / SolidWorks |
| [`Front Bumper.stl`](Front%20Bumper.stl) | Front Bumper | STL (Binary) | ~822 KB | 3D print-ready mesh for front bumper and sensor mount |
| [`Front Bumper v45.stl`](Front%20Bumper%20v45.stl) | Front Bumper (v45 Revision) | STL (Binary) | ~1.42 MB | Latest revision of front bumper mesh |
| [`Base Plate.stl`](Base%20Plate.stl) | Main Chassis Baseplate | STL (Binary) | ~1.36 MB | 3D print-ready main vehicle chassis bottom plate |
| [`Middle Plate.stl`](Middle%20Plate.stl) | Mid-Deck Chassis Plate | STL (Binary) | ~1.22 MB | 3D print-ready middle tier electronics deck |
| [`LiDAR mount.stl`](LiDAR%20mount.stl) | Slamtec RPLIDAR C1 Mount | STL (Binary) | ~1.48 MB | 3D print-ready mast mount for 360° LiDAR scanner |
| [`Back TOF.stl`](Back%20TOF.stl) | Rear ToF Sensor Mount | STL (Binary) | ~722 KB | 3D print-ready collimated rear ToF sensor bracket |
| [`Tail .stl`](Tail%20.stl) | Rear Wing / Spoiler | STL (Binary) | ~3.03 MB | 3D print-ready rear wing structure ("TEAM BLUEPRINT") |
| [`Left Stearing Hand.stl`](Left%20Stearing%20Hand.stl) | Steering Knuckle (Left Hand) | STL (Binary) | ~3.96 MB | 3D print-ready Ackermann steering knuckle (left) |
| [`Right Stearing Hand.stl`](Right%20Stearing%20Hand.stl) | Steering Knuckle (Right Hand) | STL (Binary) | ~4.03 MB | 3D print-ready Ackermann steering knuckle (right) |
| [`LEGO Gear BOX.stl`](LEGO%20Gear%20BOX.stl) | Drive Gearbox Housing | STL (Binary) | ~2.54 MB | 3D print-ready gearbox enclosure for 5:1 reduction drive |
| [`LEGO Shaft.stl`](LEGO%20Shaft.stl) | Drive Axle Coupler / Shaft | STL (Binary) | ~468 KB | 3D print-ready drive shaft / axle coupler |
| [`Motor Mount.stl`](Motor%20Mount.stl) | 25GA Motor Mount | STL (Binary) | ~416 KB | 3D print-ready motor mounting bracket |
| [`Motor Mount .stl`](Motor%20Mount%20.stl) | 25GA Motor Mount (Reinforced) | STL (Binary) | ~1.88 MB | Reinforced motor bracket variant |
| [`Connector B22.stl`](Connector%20B22.stl) | Chassis Structural Connector | STL (Binary) | ~729 KB | 3D print-ready structural bracket |
| [`Left Front Wheel.stl`](Left%20Front%20Wheel.stl) | Front Wheel Hub (Left) | STL (Binary) | ~7.44 MB | 3D print-ready front left wheel hub with bearing recess |
| [`Right Front Wheel.stl`](Right%20Front%20Wheel.stl) | Front Wheel Hub (Right) | STL (Binary) | ~9.18 MB | 3D print-ready front right wheel hub with bearing recess |
| [`Right Rare Wheel.stl`](Right%20Rare%20Wheel.stl) | Rear Wheel Hub (Right) | STL (Binary) | ~6.31 MB | 3D print-ready driven rear wheel with axle interface |
| [`Left Rare Wheel New.stl`](Left%20Rare%20Wheel%20New.stl) | Rear Wheel Hub (Left) | STL (Binary) | ~6.31 MB | 3D print-ready driven rear wheel with axle interface (left) |
| [`Left BR.stl`](Left%20BR.stl) | Rear Axle Bearing Bracket (Left) | STL (Binary) | ~1.64 MB | 3D print-ready left axle bearing support block |
| [`Center BR.stl`](Center%20BR.stl) | Rear Axle Bearing Bracket (Center) | STL (Binary) | ~1.63 MB | 3D print-ready center axle bearing support block |
| [`Right BR.stl`](Right%20BR.stl) | Rear Axle Bearing Bracket (Right) | STL (Binary) | ~1.62 MB | 3D print-ready right axle bearing support block |
| [`Right Bearing Mount.stl`](Right%20Bearing%20Mount.stl) | Rear Axle Bearing Mount (Right) | STL (Binary) | ~1.07 MB | 3D print-ready axle bearing housing |
| [`Top Plate.stl`](Top%20Plate.stl) | Upper Enclosure Roof / Cover Plate | STL (Binary) | ~1.03 MB | 3D print-ready top cabin deck & handle interface |
| [`Camera Holder ras.stl`](Camera%20Holder%20ras.stl) | Raspberry Pi Camera Mast Mount | STL (Binary) | ~702 KB | 3D print-ready forward perception camera bracket |
| [`Stearing Holder .stl`](Stearing%20Holder%20.stl) | Steering Servo & Knuckle Mount | STL (Binary) | ~1.88 MB | 3D print-ready Ackermann steering mechanism support block |

## What belongs here

- CAD source (Fusion 360 `.f3d` / STEP) for the chassis plate, steering linkage, wheels, sensor mounts, bumper, and camera mast.
- Print-ready STL exports for every printed part.
- A short note per part: material, layer height, and any orientation that matters (print settings are in [`../docs/build_guide.md`](../docs/build_guide.md#2-3d-printing-specifications)).

| Part | Process | Notes |
|---|---|---|
| Front Bumper | Print (PLA/PETG) | Full STEP assembly model + STLs included |
| Main Chassis & Mid-Deck | Print (PLA/PETG) | Base Plate + Middle Plate included |
| Rear Wing / Spoiler | Print (PLA/PETG) | "TEAM BLUEPRINT" spoiler structure (`Tail .stl`) |
| Sensor & LiDAR Mounts | Print (PETG/PLA+) | LiDAR mount + Back ToF bracket included |
| Steering Knuckles (Ackermann) | Print (PETG/PLA+) | Left & Right knuckle STLs included; 107° / 73° arms, ±35° travel |
| Drive Powertrain | Print (PLA/PETG) | 5:1 spur gear enclosure + Motor Mounts + Shaft included |
| Rear Axle Bearing Brackets | Print (PETG/PLA+) | Left, Center, Right BR & Bearing Mount STLs included |
| Front & Rear Wheels | Print (PLA/PETG) | Complete set of 4 wheels (Left/Right Front & Rear) included |
| ToF collimator snouts + 2° wedges | Print | 2.5 x 10 x 20 mm slot |
| Colour sensor hood | Print | Fixed to chassis |
| Camera / LiDAR mast | Print | ~90 mm, obstacle round |

---

### 3D Printing & Prototyping Sponsor
Special thanks to **[rapidPCB](https://www.facebook.com/profile.php?id=61591245009575)** for sponsoring the additive manufacturing and precision 3D printing of Team Blueprint’s competition components.

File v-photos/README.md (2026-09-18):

# Vehicle Photos (`v-photos/`)

Official vehicle photographs for **Team Blueprint** — WRO Future Engineers 2026.

These high-resolution photos capture our custom 3D printed red chassis ("TEAM BLUEPRINT" rear wing, camera mast, solid rear axle, front steering linkage) in competition configuration from all 6 required perspectives.

| Perspective | File | Preview |
| :---: | :---: | :---: |
| **Front** | [`front.jpg`](front.jpg) | Front View |
| **Back** | [`back.jpg`](back.jpg) | Back View |
| **Left Side** | [`left.jpg`](left.jpg) | Left Side View |
| **Right Side** | [`right.jpg`](right.jpg) | Right Side View |
| **Top** | [`top.jpg`](top.jpg) | Top View |
| **Bottom** | [`bottom.jpg`](bottom.jpg) | Bottom View |

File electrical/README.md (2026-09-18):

# electrical

The wiring, power distribution, and board design of the car. The connection diagram lives in
[`../schemes/`](../schemes/) (currently out of date — see its README); this file explains the
reasoning a diagram cannot. The full design record is [`ELECTRICAL.md`](ELECTRICAL.md), fab
rules are in [`DESIGN_RULES.md`](DESIGN_RULES.md), and the ToF collimator solver is
[`collimator.py`](collimator.py).

## Two stacked single-sided PCBs

- No plated through-holes -> no ground plane at any layer count.
- Coarse minimum trace/space -> you often cannot route between two adjacent header pins, so
  placement (not routing) is the whole problem.
- One-sided pads lift under cable strain, so high current never crosses the PCB - battery,
  motor and servo power are wired point-to-point through screw terminals.

| Board | Carries |
|---|---|
| Upper | STM32, BTS7960 motor driver, power rails, servo header, encoder, Pi UART, IMU |
| Lower | The TCA9548A multiplexer and its sensor channels, at 3.3 V |

## Power - four domains, one star ground

| Rail | Feeds | Why separate |
|---|---|---|
| Motor | BTS7960 -> 25GA -> 5:1 -> solid rear axle | Motor noise/brown-out stays off logic |
| 6.0 V | Steering servo only (JX PS-1171MG) | Servo current spikes correlate with steering; isolate them |
| 5.0 V | STM32 logic + sensor bus (local 3.3 V regulator) | Clean supply for the MCU and sensors |
| 5.1 V, 5 A | Raspberry Pi 5 + RPLIDAR C1 | Obstacle round only; unplugged for the open round |

Bulk capacitance on the motor rail, local decoupling at every IC, ceramics across the motor
terminals. **No inline fuse** — an accepted risk, recorded in Decision #26. One master switch
powers the car on; a separate momentary button starts the program.

## Pin map (STM32F411)

The carrier was re-pinned in September 2026. Only `src/open_round/OpenRound.cpp` uses the new
map so far; `ObstacleRound.cpp`, `tools/calibration/hardware_config.h` and the older bench
testers still use the earlier one.

| Function | Current carrier (`OpenRound.cpp`) | Earlier map (`ObstacleRound.cpp`) |
|---|---|---|
| Motor (BTS7960) | PA2 RPWM (fwd), PA3 LPWM (rev); EN tied high on board | PB9 RPWM, PB8 LPWM, PB1 EN |
| Servo | PA8, 1000-2000 us | PA8, 1000-2000 us |
| Start button | PB15 reserved, **not read yet** | PA5, INPUT_PULLUP, active-low |
| Encoder | TIM5 on PA0 / PA1 | TIM3 on PA6 / PA7 |
| IMU (BNO085, SPI) | PA5 SCK, PA6 MISO, PA7 MOSI, PA4 CS, PB0 INT, PB1 RST | PB3 SCK, PB4 MISO, PB5 MOSI, PB0 CS, PB13 INT, PB14 RST |
| I2C (to mux) | PB6 SCL, PB7 SDA, PB8 mux reset; TCA9548A 0x70, 400 kHz | PB6 SCL, PB7 SDA; TCA9548A 0x70, 400 kHz |
| ToF | VL53L0X front on mux ch 3 | VL53L1X left / right / front on mux ch 1 / 3 / 4 |
| Floor colour | TCS34725 on mux ch 4 | TCS34725, channel auto-detected |
| Status LEDs | PB12, PB13, PB14 | — |
| Pi link | — (not used in the open round) | `Serial`, 115200 8N1 |

Note that on the current map PA0 (encoder) is also the Black Pill's KEY button — don't press it
while running.

## Wiring rules

- No Dupont jumpers, no breadboard. Soldered or crimped into JST-XH / screw terminals with
  strain relief.
- Twist the encoder A/B leads, route them away from the motor leads, enable pull-ups.
- Threadlocker on every fastener that carries a wire or a board standoff.

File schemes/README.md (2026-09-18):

# schemes

The electromechanical connection diagram(s): every electronic component and motor, and how they
connect. WRO asks for this as one or more JPEG/PNG/PDF schematics.

## Current file

- [`wiring_block_diagram.png`](wiring_block_diagram.png) — generated by
  [`../electrical/make_block_diagram.py`](../electrical/make_block_diagram.py).

> ⚠️ **Out of date.** The diagram is the 2026-07-26 design (5× VL53L0X with XSHUT, TCS on its
> own bus, MPU9250, MG996R, Pi 4B, inline fuse). The car now uses a TCA9548A multiplexer, a
> BNO085 on SPI, a JX PS-1171MG servo, a Raspberry Pi 5 + RPLIDAR C1, and no fuse. Regenerate it
> from the pin maps in the [main README](../README.md#pin-maps).

## What belongs here

A single connection diagram showing the STM32, BTS7960 + motor, the servo, the BNO085, the
TCA9548A multiplexer with its ToF sensors and the TCS34725, the encoder, the Raspberry Pi 5 +
camera + RPLIDAR C1, and the four power rails meeting at one star ground. Export as PNG or PDF so
it renders on GitHub and prints cleanly.

Keep the diagram in agreement with [`../electrical/README.md`](../electrical/README.md) and
[`../SPECSHEET.md`](../SPECSHEET.md) - if a pin moves, update all three.

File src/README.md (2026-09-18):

# src

Everything that runs on the car, plus the tools used to tune it.

| Folder | What it is |
|---|---|
| [`open_round/`](open_round/) | STM32 firmware for the Open Challenge |
| [`obstacle_round/`](obstacle_round/) | STM32 firmware for the Obstacle Challenge |
| [`pi/`](pi/) | Raspberry Pi perception — camera, lidar, fusion, calibration dashboard |
| [`tools/calibration/`](tools/calibration/) | Eight calibration sketches plus a menu-driven suite |
| [`tools/bench/`](tools/bench/) | Single-subsystem bench sketches |
| [`sim/`](sim/) | Steering, parking and layout simulations that informed the mechanical design |

## What runs where

| Round | On the STM32 | On the Pi |
|---|---|---|
| Open | `open_round/OpenRound.cpp` | nothing — the Pi is physically disconnected |
| Obstacle | `obstacle_round/ObstacleRound.cpp` | `pi/main.py` |

Both firmware programs share the same navigation core: heading hold on the
straights, gyro-terminated 90 degree turns, and the lane-gap lateral
correction. The obstacle firmware adds the UART vision link, the offset-based
pillar avoidance and the front-proximity failsafe. The open firmware adds a
wall-recovery state.

> **Pin maps differ.** `OpenRound.cpp` (updated 2026-09-15/17) targets the
> re-pinned carrier board; `ObstacleRound.cpp` and `tools/calibration/` still use
> the earlier map. See the pin-map table in the
> [main README](../README.md#pin-maps).

## Firmware and Pi protocol

| Direction | Frame | Meaning |
|---|---|---|
| Pi to STM32 | `V,<colour>,<dx>,<area>` | colour in {R,G,N}; dx = pillar offset in px, + is right; area = blob size. **Sender not written yet** on the Pi side |
| STM32 to Pi | `# st=.. av=.. cw=.. sv=.. hd=.. F=.. L=.. R=.. fl=.. vis=.. dx=.. a=.. cn=..` | telemetry |

UART, 115200 8N1. In `ObstacleRound.cpp` the link is `Serial` (`#define PiSerial Serial`). No checksum is used yet.

## Toolchain

STM32: Arduino core for STM32 (STM32duino), board *BlackPill F411CE*. Libraries —
`SparkFun_BNO08x_Arduino_Library`, `Adafruit_TCS34725`, Pololu `VL53L0X`
(open round) or Pololu `VL53L1X` (obstacle round), plus built-in `Servo`, `SPI`
and `Wire`. The encoder uses a hardware timer directly (TIM5 in the open
round, TIM3 in the obstacle round and calibration sketches). The `.cpp` files
are Arduino sketches: copy one into a folder of the same name as `.ino` to open
it in the Arduino IDE.

Pi: Python 3 with OpenCV and Picamera2. See [`pi/README.md`](pi/README.md).

---

Full explanation of the control logic is in
[`docs/control_architecture.md`](../docs/control_architecture.md); the
calibration procedure is in [`docs/calibration.md`](../docs/calibration.md).

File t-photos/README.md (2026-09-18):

# t-photos

Team photos, as required by WRO. **Not added yet.** Add two images here:

1. `official.jpg` - one formal photo of the whole team.
2. `funny.jpg` - one informal/funny photo with all team members.

## Team

- Samman Rahin Shanto - IUT (Islamic University of Technology) - Team lead, electrical & PCB
- Syed Subeh-Sadik Sholok - MIST (Military Institute of Science and Technology) - Firmware & control
- MD. Azmain Sheikh Rubayed - NUB (Northern University Bangladesh) - CAD & fabrication

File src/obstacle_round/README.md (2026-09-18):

# obstacle_round - Obstacle Challenge firmware

`ObstacleRound.cpp` - the same navigation core as the open round, plus the Raspberry Pi vision
link, the offset-based pillar avoidance, and the front-proximity failsafe.

## What it does

Drives 3 laps while passing red pillars on the right and green pillars on the left, then stops.
Corner navigation follows the same core as the open round, with three VL53L1X (left mux ch 1,
right ch 3, front ch 4) so a turn can also fire when the inner side wall ends. There is no
parking phase yet.

> ⚠️ This program still uses the **earlier pin map** (motor PB9/PB8/PB1, encoder TIM3 on
> PA6/PA7, IMU SPI on PB3–PB5, start button PA5) and the earlier calibration
> (`TICKS_PER_CM = 31.933`, `SERVO_TRUE_STRAIGHT = 69.0`). It must be ported to the re-pinned
> carrier used by `OpenRound.cpp` before it can run on the current car.

## The two colour channels do not collide

- The floor colour sensor (TCS34725) reads the orange/blue corner lines - this drives the turns.
- The camera (on the Pi) reads the red/green pillars - this drives the avoidance.

## Offset-based avoidance

| Phase | What happens |
|---|---|
| SWERVE | Steer to the pass side (green->left, red->right) to a computed offset - the pillar dx sets how far. The side ToF only clamps a minimum wall clearance. Remember the displacement. |
| STRAIGHTEN | Ease back onto the lane heading, holding the offset |
| HOLD | Drive straight until the pillar colour has left the frame (debounced) |
| RETURN | Reverse the same remembered displacement back toward centre |
| REALIGN | Ease onto the lane heading and resume normal driving |

Why offset-based and not "hug the wall": the offset is stable across the track, whereas chasing
the side wall to a fixed distance hugs whatever wall is there regardless of the pillar and
breaks at wall gaps and corners.

## Front-proximity failsafe

During phases SWERVE to RETURN, if the front ToF reads below 200 mm the car reverses 15 cm
holding its last steering angle, adds 8 degrees to the swerve angle (max 44), and retries -
escalating until it clears, then restoring the base swerve after the pillar is passed.

## Start + safety

- Start is the momentary button on PA5 (active-low).
- The STM32 is the safety master: vision older than 250 ms is ignored, so a missing frame
  never stalls the car. The Pi-side frame sender is not written yet (see `../pi/README.md`).
- Telemetry (`#` frames) is streamed back to the Pi every 100 ms.

## Tunables worth knowing

- DX_SPAN - camera half-width in px (160, i.e. a 320 px frame); sets how dx maps to move
  distance. `pi/sensors/camera.py` captures at 640 px wide, so either scale dx on the Pi or set
  this to 320.
- AVOID_MIN_AREA_R / AVOID_MIN_AREA_G - how big a pillar must look before the car acts.
- AVOID_SIDE_NEAR_MM / AVOID_SIDE_FAR_MM / SIDE_SAFE_MM - offset range and hard wall floor.
- FRONT_STOP_MM, AVOID_STEER_BOOST, AVOID_BACKUP_CM - the failsafe behaviour.

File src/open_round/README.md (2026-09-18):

# open_round - Open Challenge firmware

`OpenRound.cpp` - the STM32-only navigation program. No Raspberry Pi, no camera; the Pi
harness is unplugged for this round so its absence is inspectable.

## What it does

Drives 3 laps (12 corners) of the walled track and stops in the start section, using only the
BNO085 IMU, one front VL53L0X ToF (mux ch 3), the TCS34725 floor colour sensor (mux ch 4), and
the motor encoder (TIM5 on PA0/PA1).

Status LEDs: PB12 blinks during the start countdown and is solid while running, PB13 lights
over orange, PB14 over blue; all three solid = finished.

## Control flow

A non-blocking cooperative state machine - `loop()` services every sensor once per pass and
advances one step. No blocking waits or `delay()` in the driving path, so the car moves
continuously (turn -> shuffle -> realign -> straight).

| State | What happens |
|---|---|
| WAIT_START | 5 s countdown, then latch lane heading and zero the encoder. ⚠️ The start button (PB15) is **not read yet** — rule 9.11 requires it before competition |
| DRIVE_TO_CORNER | Heading-hold PID; watch floor colour + front wall for a corner |
| TURNING | Eased 90 degree arc, terminated on measured IMU heading; re-reference lane heading |
| LANE_CORRECT | Short measured lateral shuffle to re-centre, sized from the learned gap |
| FINAL_STRAIGHT | Drive the measured remaining distance and stop in the start section |
| RECOVER | Front wall ≤ 200 mm: reverse with mirrored steering until ≥ 350 mm (max 30 cm, 3 tries), then resume |
| FINISHED | Motor off, wheels centred |

IMU zeroing and sensor bring-up happen in `setup()`; there is no separate INIT state.

## Key ideas

- Heading-hold PID: structure has P, I (clamped) and D on filtered yaw-rate, servo
  slew-limited; as tuned only P is non-zero (`HEAD_KP = 2.0`). Acts only on a fresh IMU sample.
- Turn trigger = colour gate + wall event: a corner line arms the turn; it fires when the
  front wall is within 700 mm, or on colour alone if the ToF failed, or after 150 cm past the
  line as a backstop. There is no side ToF on this build. Colour is locked out for 50 cm after
  each turn, so the two lines per corner cannot double-fire.
- Direction decode: the first corner line colour (orange = clockwise, blue = counter-clockwise)
  locks the turn direction and selects which side ToF is the inner wall.
- Distance bookkeeping: the encoder is zeroed only at start and at each turn completion.
- Auto-learned gap: the lateral correction reference is learned from the first corner.

## Tuning

Constants at the top of the file (`TICKS_PER_CM = 14.853`, `SERVO_TRUE_STRAIGHT = 71.0`,
colour thresholds) were measured on the re-pinned car. The colour thresholds come from
the colour-capture version of `../tools/bench/tof_test.ino` (commit `a6f685e`; the file is now a three-ToF test). The calibration sketches in
`../tools/calibration/` still use the earlier pin map, so update `hardware_config.h` before
using them on this board. `SERVO_TRUE_STRAIGHT` is found by motion, not by eye.

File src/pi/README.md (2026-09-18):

# Raspberry Pi perception stack

Camera and lidar, fused, with a browser-based calibration dashboard.

Architecture and reasoning: [docs/control_architecture.md, section 9](../../docs/control_architecture.md#9-raspberry-pi-perception-stack-srcpi).
Colour tuning procedure: [docs/calibration.md, section 10](../../docs/calibration.md#10-pillar-color-calibration-raspberry-pi-dashboard).

## Files

| File | What it is |
|---|---|
| `worldstate.py` | the lock-guarded seam between threads; unit and sign conventions are fixed here |
| `sensors/camera.py` | Picamera2 capture plus detection functions shared by robot and dashboard |
| `sensors/lidar.py` | seals the `rplidarc1` asyncio world inside one thread |
| `main.py` | fusion loop — attaches a lidar range to each camera bearing |
| `dashboard.py` | Flask calibration dashboard, MJPEG streams, live sliders |
| `templates/index.html` | the dashboard page |
| `config.json` | tuning values, written by the dashboard, read by the robot |
| `robodash.service` | systemd unit for the dashboard |

## Setup

Raspberry Pi OS Bookworm 64-bit.

```bash
sudo apt install -y python3-picamera2            # camera stack comes from apt, not pip
python3 -m venv --system-site-packages ~/robo-env
source ~/robo-env/bin/activate
pip install -r requirements.txt
```

`--system-site-packages` is required so the apt-installed `picamera2` is visible
inside the venv.

Check the lidar is where the code expects it (`/dev/ttyUSB0` at 460800 in
`sensors/lidar.py`):

```bash
ls -l /dev/ttyUSB*
```

## Run

```bash
python3 main.py         # robot: camera + lidar + fusion
python3 dashboard.py    # calibration dashboard on http://<pi>:8080
```

**Only one of these at a time.** Both want the camera. `robodash.service`
declares `Conflicts=robot.service`, so systemd enforces it once `main.py` is
also installed as `robot.service` (that unit is not in the repo yet).

## Install the dashboard as a service

The unit as committed assumes user `suntzu` and `dashboard.py` copied to
`/home/suntzu`. Edit `User=`, `WorkingDirectory=`, `Environment=PATH` and
`ExecStart=` to point at your checkout (e.g. `.../src/pi/dashboard.py` with
`WorkingDirectory` set to `src/pi`, so `config.json`, `templates/` and
`sensors/` are found), then:

```bash
sudo cp robodash.service /etc/systemd/system/
sudo systemctl daemon-reload
sudo systemctl enable --now robodash
journalctl -u robodash -f
```

## Conventions

Fixed in `worldstate.py`, enforced everywhere:

- distances in **mm**, angles in **degrees**
- lidar frame: **0 degrees is robot forward, increasing counter-clockwise**.
  If your mount differs, set `MOUNT_OFFSET_DEG` in `sensors/lidar.py`
- "no return at this angle" is `float('inf')`, never `None`

## Competition settings

- Wi-Fi and Bluetooth disabled at boot in `/boot/firmware/config.txt`
  (`dtoverlay=disable-wifi`, `dtoverlay=disable-bt`), per rule 11.10
- Run the robot process, not the dashboard
- The dashboard's MJPEG streams cost real CPU; they are for the pit only

## Open items

- The fusion loop prints to the console. It does not yet send the
  `V,<colour>,<dx>,<area>` frame to the STM32.
- `config.json` and `dashboard.py` work in **HSV**. The click-to-sample
  threshold tool we actually use works in **Lab** and is not committed here yet.
- `MOUNT_OFFSET_DEG` is 0 and has not been verified against the physical mount.
- `hfov_deg` is 62.0, which is a standard Pi camera figure, not a fisheye one.
  Confirm which lens is fitted.
- Frames are 640 × 480, but the STM32's `DX_SPAN` assumes a 320 px frame —
  scale `dx` when the sender is written.

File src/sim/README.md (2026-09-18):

# sim - steering-study simulations (historical)

These Python simulations are early design analysis, kept as part of the engineering record.
They informed the mechanical design before anything was built. They do NOT run on the car and
they do NOT describe the final steering - the build overruled their conclusion (see Decision #4
in [`DECISIONS.md`](../../DECISIONS.md) and finding #3 in
[`docs/engineering_findings.md`](../../docs/engineering_findings.md)). Preserved unedited
because the reasoning, and where it fell short, is itself useful.

Requirements: `pip install numpy matplotlib` (plus `pymunk` for `steering_dyn.py`).

| File | What it modelled |
|---|---|
| steering_study.py | Single central pivot vs Ackermann vs parallel bell-crank on scrub, parking, slop. |
| steering_dyn.py | Dynamic-friction version at parking speed. |
| rear_axle_scrub.py | Solid axle vs open differential: scrub and odometry bias (still supports Decision #10). |
| optimize_layout.py | Early geometry/CG layout optimisation. |
| geometry_sweep.py | Turn radius and two-arc park ratio R/L versus wheelbase and steering lock (Decisions #21, #28). |
| park_feasibility.py | Swept-polygon check of a symmetric two-arc parallel park (Decision #21). `--wheelbase` is required; the solver rejects wheelbases above 117 mm for a 165 mm body. |

## The lesson

`steering_study.py` scored candidates on scrub, parking and slop but never on the swept envelope
of the car body during a turn - the exact term that made the single central pivot wrong once
built. Simulate, but build the thing early.

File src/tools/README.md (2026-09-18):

# tools

| Folder | What it is |
|---|---|
| [`calibration/`](calibration/) | The eight calibration routines — the numbers the car drives on |
| [`bench/`](bench/) | Single-subsystem sketches used during bring-up |

The calibration procedure itself — the rig, the method, how to read each
result — is in [`docs/calibration.md`](../../docs/calibration.md).

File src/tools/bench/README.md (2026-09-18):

# bench

Minimal sketches used during bring-up to prove one subsystem at a time before
anything was wired together. Keep them: when something stops working on the
car, the fastest route to the cause is proving the part in isolation again.

| Sketch | Proves |
|---|---|
| `HallEncoderTester.cpp` | TIM3 hardware quadrature decoding on PA6/PA7 |
| `RearWheelDriveTester.cpp` | BTS7960 direction and PWM |
| `TCS34725_ColorSensorTester.cpp` | Colour sensor reachable behind the TCA9548A mux |
| `tof_test.ino` | Current carrier: three VL53L0X on the mux — front (ch 3) plus two new side sensors (ch 5, ch 6) — read non-blocking, with loop rate. Checks each sensor responds, agrees with a tape measure at 200 / 350 / 700 mm, and reads out-of-range down an open straight |

> [`tof_color_sensor_routine.txt`](tof_color_sensor_routine.txt) describes the earlier version of `tof_test.ino` (live colour stream + o/b/w threshold capture), which was replaced on 2026-09-18 by the three-ToF test. The colour-capture sketch is no longer in the repo; recover it from git history (commit `a6f685e`) if you need to re-measure the floor thresholds.

For measurement rather than bring-up, use
[`../calibration/`](../calibration/) instead.

> `RearWheelDriveTester.cpp` declares RPWM = PB8 / LPWM = PB9, while
> `ObstacleRound.cpp` has them the other way round — and the current carrier
> (`OpenRound.cpp`) has moved the motor to PA2 (forward) / PA3 (reverse),
> bench-confirmed. The older testers here use the earlier pin map.

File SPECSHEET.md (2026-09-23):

# SPECSHEET — WRO Future Engineers 2026

**Team:** Blueprint · **National competition: 20 August 2026 — won** · International: WRO Open Championship Asia Pacific, Hyderabad, 25–27 September 2026
**Status (2026-09-18):** Vehicle built and rebuilt for the Asia Pacific event. Sections 3 (geometry) and 1–2 (rules) are current. Several later sections are the **July design record** and have been superseded by the build — each is marked below. Where this file disagrees with the firmware, the firmware is what runs.

### Current as-built summary (2026-09-18)

| Item | As built now | Superseded entry below |
|---|---|---|
| Steering | Ackermann linkage, 107° / 73° arms, ±35° lock, R = 194.4 mm | §7 (parallelogram) |
| Servo | JX PS-1171MG digital metal-gear | §7, §11 (MG996R, analog 50 Hz ceiling) |
| IMU | BNO085 on SPI, game rotation vector ~100 Hz | §8 (MPU6050 bench / IMU not ordered) |
| I²C | TCA9548A mux; Open fw: 1× VL53L0X front (ch 3) + TCS34725 (ch 4); Obstacle fw: 3× VL53L1X L/R/F (ch 1/3/4) + TCS34725 | §8 (5× VL53L0X F/FL30/FR30/L90/R90, MPU6050 on ch 7) |
| SBC | Raspberry Pi 5 (8 GB) + RPLIDAR C1 + 160° fisheye, 5.1 V / 5 A rail | §11 (Pi 4B, 3 A) |
| Odometry | Measured `TICKS_PER_CM`: 14.853 (Open fw, current car), 31.933 (Obstacle fw, earlier build) | §4 (0.175 mm/count derivation) |
| Open-round logic | See [`docs/control_architecture.md`](docs/control_architecture.md) | §5 state list |
| Pin map | See [`electrical/README.md`](electrical/README.md#pin-map-stm32f411) | — |

*Revised 2026-07-28* — steering lock, I²C topology, IMU and electrical build all changed;
see Decisions #23–#28.

---

## 1. Rule-hard constraints (WRO FE 2026)

| Constraint | Limit |
|---|---|
| Footprint | ≤ 300 × 200 mm |
| Height | ≤ 300 mm |
| Mass | ≤ 1.5 kg |
| Wheels | 4 wheels, ONE driven axle, ONE steering actuator |
| Drive | No diff-drive, no omni. Max 2 drive motors, mechanically coupled to the same axle |
| Wireless | None during runs |
| Parking bay | 200 mm deep × (1.5 × car length). Magenta blocks untouchable (touch = 0 parking points) |
| "Parallel" | Same-side wheels within 2 cm of wall |

## 2. Scoring model (122 total)

- ~75% driving, ~25% engineering journal.
- Parking = 15 pts; +7 pts for starting inside the lot. (Not yet implemented in firmware.)
- **Strategy: full parallel park.**
- Commit deadlines (gated): 1st commit ≥ 2 months pre-comp (≥ 1/5 of code), 2nd ≥ 1 month, and the **≥ 2-weeks-before commit is the one judges score**. README ≥ 5000 chars.

## 3. Geometry — AS BUILT (2026-07-26)

> **SUPERSEDES** the 2026-07-12 optimizer-locked geometry (track 120 / wheelbase 128 /
> 175x138x95 / wheel 40 mm / single central pivot). That design was never built. The
> optimizer output in `src/sim/optimize_layout.py` is retained as a study, not a spec.
> Divergence rationale: `journal/day-02-plan-revision-2026-07-26.md`, Decision #4 block.

| Parameter | As built (CAD Verified) | Note |
|---|---|---|
| Track (Front wheel centre to centre) | **102.09 mm** | Distance between front tire contact patches |
| Track (Front extreme outer) | **114.09 mm** | CAD measured: 114.09 mm across outer tire sidewalls (scored width) |
| Track (Rear wheel centre to centre) | **84.84 mm** | Rear driven axle wheel centers |
| Track (Rear extreme outer) | **113.59 mm** | Outermost edge of rear driven hubs |
| Kingpin pivot span ($K_w$) | **80.59 mm** | CAD measured: 80.589 mm between knuckle pivots |
| **Overall Length (Bumper to Spoiler)** | **274.29 mm** | Front bumper leading edge to rear spoiler trailing tip ($\le 300\text{ mm}$) |
| **Chassis Baseplate Length** | **183.5 mm** | Main bottom structural plate length ($\times 101.7\text{ mm}$ width) |
| Avionics Mid-Deck Plate | **211.0 × 102.4 mm** | Upper electronics and sensor deck |
| **Wheelbase (front axle to rear axle)** | **136.07 mm** | CAD measured: 136.07 mm axle-to-axle |
| Front wheel dia | **48.0 mm** | Outer diameter including tire tread |
| Rear wheel dia | **48.0 mm** | Outer diameter including tire tread (drives odometry) |
| Ground Clearance | **6.02 mm** | Measured from ground contact plane to lowest chassis baseplate point |
| Front Overhang | **61.46 mm** | Front axle centre to frontmost bumper leading edge |
| Rear Overhang | **76.77 mm** | Rear axle centre to rearmost tip of spoiler |
| Steering mechanism | **Ackermann** | arms angled at 107.0° / 73.0° (17.0° inclination) |
| Steering lock | **+/-35 deg** | measured at knuckles. **Final.** |
| **Turn radius R** | **194.3 mm** | 136.07 / tan 35 deg |
| Total Car Height | **169.19 mm** | Measured to highest tip of rear wing ($\le 300\text{ mm}$) |
| Cabin / Deck Height | **104.61 mm** | Ground plane to top surface of middle avionics enclosure |
| Rear axle | solid, no diff, **5:1 gear** | Decision #14 |

**Scored footprint 274.29 × 114.09 mm (Height: 169.19 mm)** — well inside the WRO 300 × 200 × 300 mm rule ceiling.

> **Consistency Resolution (2026-09-22 CAD Audit):** Re-measured from master assembly (`ASMB.3mf` / `ASMB.step`). The structural baseplate is 183.5 mm; total envelope with front bumper and rear spoiler is 274.29 mm. Wheelbase of 136.07 mm with 48 mm wheels fits the 183.5 mm baseplate and 274.29 mm total envelope cleanly with zero interference.

### Turn radius & Kinematics — CAD VERIFIED (2026-09-15)

`R = wheelbase / tan(lock) = 136.14 / tan(35 deg) = **194.4 mm**`

Ackermann geometry condition:
$$\alpha = \arctan\left(\frac{K_w / 2}{L}\right) = \arctan\left(\frac{80.589 / 2}{136.139}\right) = \arctan(0.29597) = 16.49^\circ \approx 16.5^\circ$$
The CAD knuckle steering arms are set at **107.0° / 73.0°** ($17.0^\circ$ relative to the longitudinal axis), within $0.5^\circ$ of the ideal Ackermann convergence at the rear axle centre.

### Chassis rake — verified from CAD
Front 46 mm vs rear 50 mm = 2 mm axle height difference over the 136.14 mm wheelbase:
`rake = atan(2 / 136.14)` = **0.84 deg nose-down** (measured from CAD).
Sensor mounts incorporate a +2 deg printed wedge to tilt the ToF sensors up and clear the floor.

### Parking geometry — ⚠️ TWO-ARC PARK IS NOT FEASIBLE AT 35 deg LOCK
Bay = 1.5 x 165 = **247.5 mm** -> total longitudinal slack **82.5 mm**.
Limiters are 200 x 20 x 100 mm and the car is 50-90 mm tall, so the car **cannot pass
over them** at any point in the manoeuvre.

`src/sim/park_feasibility.py` (run at the July WB of **110 mm**; see the wheelbase note above) sweeps the parked
longitudinal position — the only free variable in a symmetric two-arc — and finds:

| Lock | R | R/L | Best clearance | Verdict |
|---|---|---|---|---|
| **35 deg (as built, FINAL)** | **157 mm** | **0.95** | **-25.6 mm** | **COLLISION** |
| 40 deg | 131 mm | 0.79 | -10.8 mm | COLLISION — considered and withdrawn |
| 45 deg | 110 mm | 0.67 | 0.0 mm | touches — no margin |
| 60 deg | 64 mm | 0.38 | +0.5 mm | clears by nothing |

The 40 and 45 deg rows are kept because they are the evidence that raising the lock does
not solve this. 40 deg still collides; 45 deg only just touches (reported as +0.1 mm in July,
0.0 mm by the current solver), which on an open-loop steering system is not clearance.
At the CAD wheelbase R rises to 194.4 mm, which makes the two-arc park worse, not better.

The front-outer corner sweeps into the entry limiter at ~37 deg heading while the rear
axle is still 164 mm along the bay.

**The problem is SCALE-INVARIANT.** Bay = 1.5 x car length always, so slack = 0.5 x car
length always. Shortening the car does not help — the bay shrinks with it. The only
levers are the ratio **R/L** and the manoeuvre strategy.

**Decision (#21 amended): the primary parking manoeuvre is a MULTI-POINT (3+) SHUFFLE,
not a two-arc.** Enter at whatever angle the geometry allows, then shuffle forward/back
against **IMU yaw** to straighten. Slower, but robust to R error — which matters because
steering is open-loop (Decision #16) and nominal R cannot be trusted. Validate on the mat.
Touching a limiter = 0 parking points (rule 9.24.7); parking is 22 of 122 points.

## 4. Drivetrain / motor - AS BUILT (July; see odometry note)

- **Motor:** 25GA, 1331 RPM, 180 counts/rev, encoder on the motor.
- **Reduction:** **5:1 gear meshed to the solid rear axle** (Decision #14 confirmation).
- Rear wheel speed = 1331 / 5 = **266 RPM**.
- **Top speed** = 266/60 x pi x 0.050 = **0.70 m/s**.
- Encoder edge rate at full speed = **3995 Hz** (encoder is upstream of the 5:1) - trivial for TIM3.

### Odometry
> **SUPERSEDES** the 2026-07-12 figure "180 / (pi x 45) ~ 0.79 mm/count", which used a
> 45 mm wheel (never built) and had no 5:1 term.

If 180 counts/rev is measured **at the motor**, then after the 5:1 there are
**900 counts per rear-wheel revolution**:

`900 / (pi x 50) = 5.73 counts/mm = **0.175 mm/count**`

FLAG - OPEN QUESTION #1, open since 2026-07-12: the hand-rotate test has still not been
done. If 180 turns out to be per WHEEL rev the constant is 5x coarser (0.87 mm/count).
Everything else in this file is independent of the answer; only this constant changes.

> **Measured since (calibration step 2):** the firmware constants are **31.933 ticks/cm =
> 0.313 mm/count** (earlier build, `ObstacleRound.cpp`) and **14.853 ticks/cm = 0.673 mm/count**
> (current car, `OpenRound.cpp`, 248.8 ticks/rev over a 5.2 cm wheel). Neither matches the
> 0.175 mm/count derived here, so the 180 counts/rev assumption above does not hold for the
> encoder as wired. Use the measured values.

**Why the 5:1 is the highest-value decision in the build:** ungeared, the car ran at
2.79 m/s with 0.70 mm/count and a 7.2 ms line-detection window. Geared, it runs at
0.70 m/s with 0.175 mm/count and a 28.6 ms window. It converted three separate problems
(uncontrollable speed, coarse odometry, unreadable colour lines) into non-problems.

**Closed-loop speed control on the encoder is mandatory** - see Decision #22 (BTS7960
has poor resolution at the ~14% duty that parking needs).

## 5. Navigation strategy - July design (current logic: [`docs/control_architecture.md`](docs/control_architecture.md))

Core (unchanged from Decision #1): gyro heading-hold on straights, 90 deg turns
**terminated by IMU** (not by steering angle, so tyre slip cannot corrupt them),
heading **re-referenced to the nearest 90 deg at every corner** to bound gyro drift.

**CHANGED 2026-07-26:** the turn trigger is now the **TCS34725 floor colour sensor**,
not front wall distance. Front ToF is demoted to confirmation / anti-collision.

### Open round state machine (12 turns = 3 laps x 4 corners)

1. `ARMED` - wait for start button (rule 9.11). Gyro bias auto-zeroed while stationary;
   the car is placed switched off (rule 9.6) so it is guaranteed still. This is firmware
   self-calibration, not team calibration, so rule 9.9 is satisfied.
2. `CENTRE` - L90 + R90 ToF equalise lateral error, then latch heading as reference.
3. `STRAIGHT` - heading-hold on IMU; encoder integrates distance; front ToF monitors
   closing distance as a backstop.
4. `LINE_EVENT` - TCS sees orange or blue.
   - **First pair of the run decodes direction.** Driving direction is drawn randomly
     before each round (rule 9.3). Orange-then-blue vs blue-then-orange sets left vs
     right for all 12 turns. Without this, 50% of runs steer the wrong way.
   - **Hard lockout.** Each corner carries BOTH an orange and a blue line (rule 13.9),
     so a naive trigger fires ~24 times over 3 laps, not 12. All colour input is ignored
     from turn start until the turn completes AND the car has driven clear.
5. `TURN` - steer to lock, integrate yaw, terminate at 90 deg, re-reference heading.
6. Increment turn counter. At 12, `STOP` inside the starting section (rule 9.24.3).

### Timing headroom
20 mm line at 0.70 m/s = **28.6 ms dwell**. TCS at 2.4 ms integration = ~11 samples.
Use single-sample edge detection with hysteresis. **Do not median-filter the colour
sensor** - a median filter smears the event away.

### "Straight" is found by motion, not by eye
Sweep servo microseconds, drive ~3 m, log average gyro yaw-rate, bisect to the
zero-crossing - that microsecond value is the true `CENTER_US`. No car is mechanically
straight; this matters more now that steering is open-loop (Decision #16).

## 6. Compute split

- **Open round:** STM32 only (ToF + floor colour + IMU + encoder). Fully deterministic, NO Pi in the loop.
- **Obstacle round:** adds **Raspberry Pi 5 (8 GB)** + **Slamtec RPLIDAR C1 (360° DTOF)** + **160° FOV fisheye camera** for 2D obstacle mapping, pillar classification, and clearance geometry.
- Inter-board link = **UART** (a checksum was planned; the current `V,…` frame has none). NEVER inter-board I2C.
- STM32 chosen over ESP32: clean 12-bit ADC (for the Sharp IR fallback), hardware quadrature encoder timers, deterministic timing (no WiFi stack stealing cycles).

## 7. Steering - July build (SUPERSEDED)

> **SUPERSEDED 2026-09** by the Ackermann linkage and JX PS-1171MG digital servo — see §3 and
> [`docs/engineering_findings.md`](docs/engineering_findings.md#3-evolution-of-three-steering-geometries).
> Kept for the reasoning. (This section itself superseded the 2026-07-12 "single central pivot +
> AS5600" specification.)

- **Parallelogram (equal-angle tie-bar) linkage.** Measured lock **+/-35 deg**.
- **Servo: MG996R** - metal-gear, **analog**. Commanded in microseconds
  (1 us timer tick, ARR = 19999).
- **Frame rate is 50 Hz and cannot be raised** - MG996R is analog. This sets a hard
  20 ms floor on steering command latency regardless of how fast the IMU is read.
  Deadband ~5 us; slew ~150 ms/60 deg at 6 V, so a full +/-35 deg sweep is ~175 ms.
- **No AS5600. Steering is fully open-loop** (Decision #16). The loop is closed on
  vehicle heading by the IMU, so steering only has to be monotonic and repeatable.
- **Firmware requirement:** an analog servo inside any closed loop will hunt across its
  deadband - current draw, heat, audible buzz, steering jitter. Quantise output to
  >= 6 us steps and hold inside a +/-1.5 deg error window.

**Why parallelogram over the simulated central pivot** (full argument in Decision #4
supersession): a central pivot swings each front wheel fore/aft by `(track/2) x sin d`.
At track 105 mm and 35 deg lock that is **+/-30.1 mm per wheel = 36% of the 82.5 mm
parking slack**, spent for no navigational gain. `src/sim/steering_study.py` never
modelled swept envelope, which is why it ranked parallel bell-crank as dominated.

**Costs accepted:** 4+ joints vs 1; no steering feedback; equal-angle scrub unchanged
(parallelogram is NOT Ackermann); turn radius nominal rather than measured.

## 8. Sensors - July design (partly SUPERSEDED — see the summary table at the top)

> **REVISED 2026-07-28 & 2026-09-05 (Decisions #23, #24, #29).** XSHUT address reassignment is replaced by a
> **PCA9548A multiplexer** — one sensor per channel, every device at its factory 0x29, five
> XSHUT GPIO reclaimed and the volatile-address-on-brownout problem deleted rather than
> managed. Obstacle challenge upgraded with **Raspberry Pi 5 (8GB)**, **Slamtec RPLIDAR C1**, and **160° FOV camera**.

| Sensor | Part | Bus | Role |
|---|---|---|---|
| Distance x5 (6th planned) | **VL53L0X** | PCA9548A ch0-ch5, all @ 0x29 | F / FL30 / FR30 / L90 / R90 |
| Floor colour | **TCS34725** | PCA9548A ch6 | turn trigger + direction decode |
| Heading — **race** | **BNO08x / ICM-42688** | **SPI1, mainboard, no mux** | gyro-Z only 🚩 **not yet ordered** |
| Heading — bench only | **MPU6050** (`WHO_AM_I` 0x68) | PCA9548A ch7 | bring-up only, **will not race** |
| Odometry | 25GA encoder | TIM3 quadrature | distance + closed-loop speed |
| Obstacle 2D LIDAR | **Slamtec RPLIDAR C1** | USB to Pi 5 | 360° DTOF, 12 m range, obstacle avoidance (obstacle round) |
| Pillar colour & offset | **Fisheye 160° FoV camera** | CSI / USB to Pi 5 | Red/green pillar classification (obstacle round) |
| High-level compute | **Raspberry Pi 5 (8 GB)** | Checksummed UART to STM32 | High-level perception & advisory steering guidance |

**Why the racing IMU stays off the mux:** Decision #1 terminates all 12 corners and every
park arc on measured heading, so the gyro is the most latency-critical signal in the
vehicle. Behind a mux it would queue behind five ToF sensors and a cable. The bench
MPU6050 can afford that; the racing part cannot.

🚩 **The competition IMU is the longest-lead item left and is not ordered.** Contingency:
I2C2 is routed to the same header, so the MPU6050 can move onto a dedicated bus by
swapping a cable rather than re-etching a board.

🚩 **One regression to watch:** the TCS34725 previously had a private bus specifically so
no ToF cable fault could take down the turn trigger. It now has address isolation but not
fault isolation. `MUX_RST` is wired to the STM32 for exactly this reason. If bench testing
shows ToF faults hanging the bus, move the TCS back to its own bus on PB10 — one spare pin.

> **CORRECTS** the 2026-07-12 entry, which specified VL53L1X. The parts on hand are
> **VL53L0X**, which has **no programmable ROI** - the mitigation assumed in that entry
> does not exist on this part.

### The floor-return problem, quantified
The mat is white (rule 13.2); both exterior and interior walls are black on every
visible face (rules 13.4, 13.6). **The false target reflects NIR better than the real
one.** Bare L0X FoV is ~25 deg fixed:

`d_floor = h / tan(theta_eff)`, side wall at (1000 - 115)/2 = **442.5 mm**

| Configuration | theta_eff | d_floor @ h = 40 mm | vs 442.5 mm |
|---|---|---|---|
| Bare L0X | 12.5 deg | 180 mm | catastrophic |
| Snout only | 3.58 deg | 640 mm | ok, thin under rake |
| **Snout + 2 deg wedge** | **2.67 deg** | **859 mm** | **+416 mm** |

**Mitigation is mechanical and mandatory (Decision #18):** printed collimator snout
**2.5 mm tall x 10 mm wide x 20 mm deep** + **+2 deg upward mounting wedge**.
Slot must be WIDE, not round - emitter and receiver apertures are ~2.5 mm apart.
Solver + regenerable table: `electrical/collimator.py`.

Firmware layer on top: reject on `RangeStatus != 0`, low signal rate, or high sigma;
median-of-3. **Re-run offset calibration after fitting the snout** - it changes crosstalk.

### Duty split between the 90 deg and 30 deg pairs (Decision #19)
- **L90 / R90** - open-corridor lane centring. 442.5 mm lateral, inside d_floor.
- **FL30 / FR30** - obstacle-corridor centring when threading a pillar-to-wall gap.
  Slant range = gap / sin 30 deg = 2 x gap: a 150 mm gap reads at 300 mm, a 350 mm gap
  at 700 mm. They degrade exactly when the gap is wide, which is when L90/R90 take over.
- FLAG to bench-test: at 30 deg off-axis the beam hits the wall at 60 deg from normal,
  so return falls by cos 60 = 0.5 on an already-black surface.

### Highest-risk open item in the whole build
**Bench-test VL53L0X signal rate against black MDF, snout fitted, at 442 mm (90 deg pair)
and at 300 / 700 mm at 60 deg incidence (30 deg pair), BEFORE printing five mounts.**
The snout throws away photons and the wall is already a poor NIR target. If signal rate
is marginal, the Sharp GP2Y0A21 fallback must be ordered immediately - and its lead time
is still unrecorded in `BOM.md` (Open Question #3).

### Unchanged
- **LIDAR integrated (Obstacle Challenge):** Slamtec RPLIDAR C1 (360° DTOF, ~110 g) mounted on upper deck (Decision #29).
- **Sensors + camera mount to the FIXED chassis**, never the steering linkage.

## 9. Reliability spec ("no randomness")

- Ball bearings on every axle AND the steering pivot (plastic-on-shaft wears in and grows slop mid-competition).
- Locate parts by GEOMETRY (shoulders, slots, captured screws) — glue is backup only, never primary.
- Threadlocker / nail polish on every thread; nyloc nuts where possible.
- NO Dupont jumpers, no breadboard on the robot. Solder, or JST/screw terminals with strain relief.
- Separate motor and logic power domains, joined at ONE star ground. Bulk cap 470–1000 µF on motor supply, 0.1 µF near MCU.
- 0.1 µF ceramic caps across motor terminals (EMI suppression).
- Twist encoder A/B leads, route away from motor leads, enable pull-ups.
- **Design principle for a novice assembler: a loose joint must STILL not be able to shift.**

## 10. Reference repos (fetch live, don't copy files)

- KMIDS-GFM 2025 — github.com/Chayanon-Ninyawee/KMIDS-GFM-Future-Engineer-2025 (right-sized, fisheye + lidar + Pi, FreeCAD models — closest analog)
- Nerdvana Taurus 2025 — github.com/andreipopescufilimon/WRO2025_Future_Engineers (best mechanical/steering docs; restrictive licence — study, re-model, do NOT reuse files)
- Official archive of all 64 finalist repos — WRO-Association fe-2025-links

## 11. Electrical architecture - July design

Full detail: `electrical/ELECTRICAL.md`. Block diagram: `schemes/wiring_block_diagram.png` (dated 2026-07-26).
The Pi 4B / MG996R / MPU6050 figures below are superseded by the Pi 5 + RPLIDAR C1 (5.1 V / 5 A
rail), the JX PS-1171MG and the BNO085.

### Power domains - ONE master switch (rule 9.10)
```
  [connector]              MASTER SWITCH (rule 9.10: only one switch may power the vehicle on)
[3S LiPo 75C]--+------------[SPST 10A]--+--> DOMAIN M : BTS7960 -> 25GA -> 5:1 -> solid rear axle
               | (NO FUSE, #26)         +--> BEC-S 6.0V/3A -> MG996R servo ONLY
           (star GND)                   +--> BEC-L 5.0V/2A -> Board A logic + Board B (3V3 local)
               |                        +--> BEC-C 5.1V/3A -> Pi 4B + fisheye  [OPEN ROUND: REMOVED]
               +-- all BEC grounds + battery negative meet at ONE M3 brass standoff
```

🚩 **Fuse deliberately omitted (Decision #26)** — accepted risk, not an oversight. A 75C 3S
pack will deliver several hundred amps into a short with no current limiting.
🚩 **Battery connector unresolved** — JST-XH is ~3 A per contact against ~8 A peak draw;
XT30 (30 A) remains the specified part until decided otherwise.

### Physical build — two stacked single-sided boards (Decision #25)
Our fab does double-sided **without plated through-holes**, so two-layer is unusable and
**no ground plane is available at any layer count**. At 0.5 mm minimum trace and space,
**no trace can pass between two adjacent header pins**, so placement rather than routing
is the design problem.

- **Board A (upper):** STM32, BTS7960, BEC rails, servo, encoder, Pi UART, competition IMU
- **Board B (lower):** PCA9548A + 8 channels + local AMS1117-3.3
- Joined by a ~40 mm **6-pin JST-XH**. High current never crosses PCB copper.

Full detail: `electrical/ELECTRICAL.md`. Fab rules: `electrical/DESIGN_RULES.md`.

The Domain C harness is **physically absent** for the Open Challenge. That is an
inspectable claim, not a software flag: the Open configuration cannot be influenced by
the Pi because the Pi is not electrically present.

### Power budget
| Domain | Load | Typ | Peak |
|---|---|---|---|
| M | 25GA via BTS7960 | ~0.6 A | FLAG - stall not yet measured |
| S | MG996R | 0.5-0.9 A | ~2.5 A stall |
| L | STM32 40 mA + 5x VL53L0X 100 mA + TCS 3 mA + MPU6050 4 mA + PCA9548A 1 mA | **~150 mA** | ~250 mA |
| C | Pi 4B 1 GB + camera | 0.85 A | ~1.25 A |

Pi 4B: set BEC-C to **5.15 V measured at the header under load**, feed pins 2/4/6 with
18 AWG. Never exceed 5.25 V - this bypasses the USB-C input protection.

### Loop rates
| Loop | Rate | Bound by |
|---|---|---|
| IMU gyro-Z + heading integrate | 1000 Hz | SPI, fixed timer tick (constant timestep) |
| Encoder | 1000 Hz | free, TIM3 hardware |
| Drive speed PID | 200 Hz | mandatory - see Decision #22 |
| **Servo command** | **50 Hz** | **MG996R analog - the steering bottleneck** |
| VL53L0X x5 | 30-50 Hz | sensor |
| TCS34725 | >= 100 Hz | 2.4 ms integration |
| Pi colour frame | 15-30 Hz | advisory only, never gates a control loop |

### Reliability, unchanged from Section 9
Star ground; motor return on its own >= 1.0 mm^2 leg, never through logic ground;
1000 uF + 0.1 uF at the BTS7960 input; 470 uF + 0.1 uF at the servo connector;
0.1 uF across motor terminals and 2x terminal-to-can; encoder A/B twisted with
10k pull-ups + 100R/1nF; no Dupont anywhere.

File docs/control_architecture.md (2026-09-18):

# Control Architecture & Intelligence — How the Car Thinks

> This document details the autonomous decision architecture, real-time state machine, odometry-based lane correction, and dual-tier perception stack of **Team Blueprint**.
> For a high-level system overview, return to the **[Master README](../README.md)**.

---

## 1. Core Navigation Philosophy

> **"The heading is the truth. Everything else is a hint."**

In autonomous miniature vehicle racing, raw sensor feedback is inherently prone to environmental noise:
* Wheels slip under acceleration and corner entry.
* Tyres scrub sideways through turns on low-friction mats.
* Time-of-Flight (ToF) distance sensors pick up specular reflections off high-reflectance white vinyl mats.
* Optical cameras can drop color tracks due to sudden ambient illumination changes or shadows.

To achieve robust 3-lap repeatability across 12 corners, **heading decides when a manoeuvre is finished, while other sensors only decide when one should start**:
* A $90^\circ$ turn terminates when the IMU registers $90^\circ$ of yaw displacement (within $0.3^\circ$). Encoder distance is only a safety cap (120 cm) in case the IMU never gets there.
* Straightaways are maintained via closed-loop gyroscope heading hold, rather than by continuously following wall distances.
* Drift is bounded by stepping the lane heading by exactly $90^\circ$ at every corner, so each straight is held against a fixed target.

---

## 2. Dual-Tier Heterogeneous Compute Hierarchy

```
            +-------------------------------------------+
            |  Raspberry Pi 5            ADVISORY tier   |
            |                                            |
            |  camera thread  ->  colour + bearing       |
            |  lidar thread   ->  360° ranges            |
            |  fusion loop    ->  obstacles with distance|
            +--------------------+-----------------------+
                                 |  UART 115200 baud (planned sender)
                                 |  "V,<colour>,<dx>,<area>"
                                 v
            +-------------------------------------------+
            |  STM32F411CEU6             REAL-TIME tier  |
            |                                            |
            |  IMU heading, encoder odometry,            |
            |  ToF ranges, floor colour,                 |
            |  the state machine, servo, motor           |
            +-------------------------------------------+
```

The system separates deterministic vehicle control from computationally heavy perception:

1. **STM32 Real-Time Master ([`src/open_round/OpenRound.cpp`](../src/open_round/OpenRound.cpp) / [`src/obstacle_round/ObstacleRound.cpp`](../src/obstacle_round/ObstacleRound.cpp))**:
   * Directly drives the motor (BTS7960 H-bridge, RPWM/LPWM) and steering servo (JX PS-1171MG).
   * Executes a zero-allocation, non-blocking cooperative state machine.
   * Reads the IMU (BNO085 over SPI, game rotation vector at ~100 Hz), the motor quadrature encoder (hardware timer), ToF distance sensors, and the TCS34725 floor colour sensor.
2. **Raspberry Pi 5 Advisory Tier ([`src/pi/`](../src/pi/))**:
   * Runs camera colour-blob detection and a LiDAR range thread, and fuses them into obstacles with bearing and distance.
   * Is meant to emit advisory serial packets (`V,<colour>,<dx>,<area>`). **Not implemented yet:** `main.py` currently prints the fused obstacles to the console and does not open the UART.
3. **Fail-Safe Decoupling**:
   * If the Pi freezes or stops sending, the STM32 treats vision as stale (`visionFresh() == false` after 250 ms) and simply never engages avoidance — it keeps driving on its own navigation.
   * The STM32 never waits on the Pi, so a perception fault cannot stall the drive loop.

---

## 3. The Autonomous State Machine

```mermaid
stateDiagram-v2
    direction LR
    [*] --> WAIT_START
    WAIT_START --> DRIVE_TO_CORNER : start button (Obstacle fw)<br/>5 s countdown (current Open fw)
    DRIVE_TO_CORNER --> TURNING : corner line armed AND<br/>front ToF ≤ 700 mm / side wall gone / backstop
    DRIVE_TO_CORNER --> AVOID : pillar engaged, no corner imminent<br/>(obstacle round only)
    AVOID --> DRIVE_TO_CORNER : manoeuvre complete
    TURNING --> LANE_CORRECT : heading moved 90°
    LANE_CORRECT --> DRIVE_TO_CORNER : shuffle + realign done
    LANE_CORRECT --> FINAL_STRAIGHT : after corner 12
    FINAL_STRAIGHT --> FINISHED : measured distance run out
    DRIVE_TO_CORNER --> RECOVER : front < 200 mm (Open fw)
    RECOVER --> DRIVE_TO_CORNER : backed off
    FINISHED --> [*]
```

### Invariant Rules
1. **Corner Priority**: In `DRIVE_TO_CORNER` the turn triggers are evaluated before the pillar check, and avoidance is not entered once a corner line has armed the turn and the front wall is within `FRONT_TURN_MM`. (An avoidance that is already running completes before the next corner is looked for.) Missing a pillar forfeits points; missing a corner ends the run.
2. **Sensor-Driven State Exits**: Apart from the start countdown and short debounce windows, transitions are governed by measurements (encoder distance, IMU yaw, colour transitions, ToF range), each with an encoder-distance backstop so no state can hang.
3. **The Open-round program has no `INIT` state** — hardware bring-up happens in `setup()`; the obstacle program has an explicit `STATE_INIT`.

---

## 4. Startup, Calibration & Direction Decoding

1. **Sensor Initialization**: At power-on, the STM32 brings up the TCA9548A I2C multiplexer, the ToF sensor(s) (one VL53L0X in the Open program, three VL53L1X in the Obstacle program), the TCS34725 floor sensor, and the BNO085 IMU over SPI. Non-responding sensors are logged and the car degrades (e.g. with no front ToF the turn fires on colour alone).
2. **Gyro Zeroing**: The vehicle records the initial stationary yaw as `initialYawOffset`. All subsequent headings are relative to this startup vector, normalized to $[-180^\circ, +180^\circ]$. The car must remain stationary during boot.
3. **Wait for Start (`STATE_WAIT_START`)**: The motor stays off until the start pushbutton is pressed (WRO Rule 9.11). ⚠️ The current Open-round firmware does not read the button yet and instead starts after a fixed 5 s countdown — this must be changed before competition.
4. **Autonomous Direction Decoding**:
   The driving direction (clockwise vs. counter-clockwise) is drawn randomly per round (WRO Rule 9.3). The mat features an orange line and a blue line at each corner. The colour of the first line crossed at corner 1 determines the entire round:
   * **Orange first** $\to$ Clockwise $\to$ All subsequent corners are $90^\circ$ right turns.
   * **Blue first** $\to$ Counter-Clockwise $\to$ All subsequent corners are $90^\circ$ left turns.
   Once locked, the state machine only checks for its expected corner color, preventing stray reflections from corrupting the run.

---

## 5. Main Cruise Loop: `STATE_DRIVE_TO_CORNER`

Between corners, the vehicle holds the current lane heading with a heading controller (PID structure, run with only the P term):

$$\text{error} = \text{target heading} - \text{current heading}$$
$$\text{servo} = \text{SERVO TRUE STRAIGHT} + K_{p,\text{head}} \cdot \text{error}$$

* Slew-rate limited to `SERVO_SLEW` ($2.5^\circ/\text{cycle}$) to suppress yaw jerk and wheel scrub.
* $K_i = 0$ and $K_d = 0$ as tuned: the D term would act on filtered yaw rate (`YAW_FILT_ALPHA = 0.35`) and mechanical offset is calibrated out through `SERVO_TRUE_STRAIGHT`.
* The controller only acts on a fresh IMU sample.

### Concurrently Monitored Events
* **Corner Detection**: A floor line of the expected colour (debounced for `COLOR_CONFIRM_MS` = 6 ms) *arms* the corner. The turn then *fires* when the front ToF reads ≤ `FRONT_TURN_MM` ($700\text{ mm}$), or — in the Obstacle program — the inner side ToF goes invalid for 40 ms (the wall has ended). Backstops: if no range sensor is working the turn fires on colour alone, and the Open program fires anyway after `GATE_TO_TURN_MAX_CM` = 150 cm past the line.
* **Post-Corner Lockout**: For `POST_CORNER_LOCKOUT_CM` ($50\text{ cm}$) after each turn, colour detections are masked. This prevents sweeping back over the same corner lines on exit and triggering an accidental immediate second turn.
* **Obstacle Encounter (Obstacle Round)**: A fresh vision frame reports R or G with an area ≥ `AVOID_MIN_AREA_R/G` (1600).
* **Wall Recovery (Open Round)**: If the front ToF reads ≤ `WALL_PANIC_MM` (200 mm), the car enters `STATE_RECOVER`: it reverses with mirrored steering until the wall is ≥ 350 mm away (max 30 cm, max 3 consecutive failed attempts), ignoring floor lines it re-crosses on the way back, then resumes the interrupted state.

---

## 6. Lane-Gap Correction

<p align="center">
  Radial corner lines used as a ruler for lateral position
</p>

### The Problem with Wall-Following
Over 12 corners (3 full laps), slight turn variations compound. A wide corner exit leaves the car closer to the outer wall, degrading the entry angle of the next corner. Traditional robots follow the side wall with distance sensors; however, on matte black walls with white vinyl floors, ToF sensors are susceptible to beam clipping and false reflections.

### The Geometric Insight
The orange and blue corner marker lines **fan out radially**. The further the car is from the inner wall, the greater the physical distance between the two lines.

Thus, the distance between the two line crossings acts as a precise lateral ruler. The measurement is performed entirely by the motor encoder—the one sensor immune to optical surface noise.

### Implementation Logic
1. **Self-Referenced Baseline**: On Corner 1, the car measures the encoder distance between crossing line 1 and line 2 and stores it as the reference (`gapRefCm`). Until then the reference defaults to `GAP_THRESHOLD_CM` (20 cm). The vehicle does not assume an idealized track position; it holds the line it started on.
2. **Error Calculation**: On every subsequent corner:
   $$\text{gap error} = \text{measured gap} - \text{reference gap}$$
3. **Proportional Steering Offset**:
   $$\theta_{\text{offset}} = \min(K_{\text{lat}} \cdot |\text{gap error}|,\  30^\circ) \quad (K_{\text{lat}} = 4^\circ/\text{cm})$$
   The servo is held $\theta_{\text{offset}}$ off `SERVO_TRUE_STRAIGHT` (side chosen from the sign of the error and the driving direction) for `CORRECTION_DISTANCE_CM` ($25\text{ cm}$) at reduced speed (`CORRECTION_PWM` = 55 Open / 70 Obstacle), then an eased arc brings the car back onto the lane heading.
4. **Deadband & Missing Lines**:
   * Errors under `GAP_DEADBAND_CM` ($2\text{ cm}$) are ignored to prevent hunting.
   * If the partner line is never seen during the turn, the correction for that corner is skipped.
   * While correcting, the car keeps watching for the next corner's line so a corner reached mid-correction is not missed (Open program).

---

## 7. Turn Dynamics: `STATE_TURNING`

Turns are executed with a non-blocking, eased proportional control law terminating strictly on IMU yaw:

$$\text{steer} = \text{clamp}(K_{p,\text{turn}} \cdot |\text{error}|,\  \text{TURN MIN STEER},\  \text{TURN MAX STEER})$$
$$\text{pwm} = \text{clamp}(K_{v,\text{turn}} \cdot |\text{error}|,\  \text{TURN MIN PWM},\  \text{TURN MAX PWM})$$

* As the vehicle approaches the target heading, speed and steering angle smoothly taper down to prevent exit overshoot.
* **No Settle Delay**: The turn hands off immediately when $|\text{error}| < 0.3^\circ$ (or after a 120 cm encoder cap). Residual error is absorbed while driving down the next straight.
* After corner 12 and its lane correction, the vehicle enters `STATE_FINAL_STRAIGHT`. The distance to drive is learned during the run as $L - A$ (full start-straight length measured at corners 5 and 9, minus the start-to-first-corner distance); `FINAL_STRAIGHT_CM` = 100 cm is only the fallback if $L$ was never measured.

---

## 8. Pillar Avoidance (Obstacle Round)

### Perception Link Protocol
The STM32 parses ASCII frames from the Pi over UART (115200 8N1). The Pi-side sender is **not written yet**; the format the firmware expects is:
```
V,<colour>,<dx>,<area>
```
* `colour`: `R` (Red), `G` (Green), or `N` (None).
* `dx`: Pixel displacement from frame centre; the firmware normalises it with `DX_SPAN` = 160 (a 320 px wide frame). Note that `camera.py` currently captures at 640 × 480, so either the sender must scale `dx` or `DX_SPAN` must become 320.
* `area`: Segmented contour area (used as proximity proxy).

### Offset-Based Maneuvering
Rather than applying a fixed swerve angle, the evasion target is calculated dynamically from the horizontal pixel offset $dx$:
* Centered obstacle ($|dx| \approx 0$) $\to$ Aggressive swerve aiming for `AVOID_SIDE_NEAR_MM` ($150\text{ mm}$ clearance from wall).
* Offset obstacle ($|dx| \gg 0$) $\to$ Mild swerve aiming for `AVOID_SIDE_FAR_MM` ($300\text{ mm}$ clearance).
* Hard safety limit: Vehicle will never steer closer than `SIDE_SAFE_MM` ($100\text{ mm}$) to any wall.
* **Rules Compliance**: Red pillars are passed on the right; green pillars on the left.

### 6-Phase Avoidance State Machine

The frame has no checksum; the parser simply rejects anything that does not match `V,<R|G|N>,<int>,<int>`.

```mermaid
stateDiagram-v2
    direction LR
    [*] --> P1
    P1 : 1 · SWERVE OUT
    P2 : 2 · STRAIGHTEN
    P3 : 3 · HOLD
    P4 : 4 · RETURN
    P5 : 5 · REALIGN
    P6 : 6 · BACKUP
    P1 --> P2 : offset reached,<br/>capped, or pillar gone
    P2 --> P3 : on lane heading
    P3 --> P4 : colour gone 150 ms
    P4 --> P5 : displacement returned
    P5 --> [*] : back to DRIVE_TO_CORNER
    P1 --> P6 : front ToF < 200 mm
    P2 --> P6 : front ToF < 200 mm
    P3 --> P6 : front ToF < 200 mm
    P4 --> P6 : front ToF < 200 mm
    P6 --> P1 : reversed 15 cm,<br/>swerve boosted +8°
```

| Phase | Action | Exit Condition |
|:---|:---|:---|
| **1. Swerve Out** | Steer out to computed offset; integrate lateral displacement via encoder. | Offset reached, boundary cap reached, or pillar exits frame. |
| **2. Straighten** | Align parallel to lane heading while holding lateral offset. | Yaw error $< 0.3^\circ$ (same eased arc as a turn). |
| **3. Hold** | Cruise along the obstacle side. | Color absent for debounced duration (`AVOID_RELEASE_MS = 150 ms`). |
| **4. Return** | Steer back by the exact integrated displacement. | Symmetric return distance completed. |
| **5. Realign** | Re-lock onto lane heading; restore base steering trims. | Aligned with lane; hands back to `DRIVE_TO_CORNER`. |
| **6. Backup** | **Near-miss recovery**: if the front ToF drops below $200\text{ mm}$ during phases 1–4 (and the car has moved ≥ 5 cm forward since the last backup), it is about to clip something. | Reverse $15\text{ cm}$ holding the last steering angle, boost the swerve angle by $+8^\circ$ (up to $44^\circ$), and re-attempt Phase 1. The base angle is restored after the pillar is passed. |

---

## 9. Raspberry Pi Perception Stack ([`src/pi/`](../src/pi/))

### Concurrency Architecture (`worldstate.py`)
A lock-guarded shared state (one slot per producer) connects the sensor threads to the fusion loop:
* Producers overwrite slots under a fast mutex lock.
* `snapshot()` extracts object references without blocking sensor capture loops.
* Enforces universal coordinate standards: distances in millimeters, angles in degrees ($0^\circ$ forward, positive left), and invalid returns as `float('inf')` (never `None`).

### Optical Vision Pipeline (`sensors/camera.py`)
* Camera acquisition via `Picamera2` at $640 \times 480$, HSV thresholding from `config.json`, published at up to ~30 Hz.
* Module-level detection functions share bit-for-bit identical code between the autonomous run loop and the tuning dashboard.
* Calculates angular bearing from optical principal point:
  $$\text{bearing} = -\left(\frac{c_x - \frac{W}{2}}{\frac{W}{2}}\right) \cdot \frac{\text{HFOV}}{2}$$
* `hfov_deg` in `config.json` is 62°, a standard Pi-camera figure — it must be changed to the real field of view if the 160° fisheye is fitted (and a linear pixel-to-angle map is only approximate for a fisheye).

### Asynchronous LiDAR Pipeline (`sensors/lidar.py`)
* Wraps the asyncio-based `rplidarc1` library inside a dedicated OS thread.
* Reads `/dev/ttyUSB0` at 460800 baud and streams points into a 360-element range array indexed by integer degree ($0^\circ$ = forward, counter-clockwise positive, `MOUNT_OFFSET_DEG` = 0 not yet verified).
* Publishes to shared state at 50 Hz.

### Sensor Fusion (`main.py`)
At 30 Hz, the fusion loop gives each camera obstacle the minimum LiDAR range within $\pm 8^\circ$ of its bearing, producing (colour, bearing, distance) tuples. It currently prints them; the next step is to turn the nearest pillar into a `V,…` frame for the STM32.

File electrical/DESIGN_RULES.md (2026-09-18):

# DESIGN RULES — single-sided, local Dhaka fab

**Date:** 2026-07-28 · Destination: `electrical/DESIGN_RULES.md`
Derived from the shop's published capability sheet (2026-07-28).

Both boards: **1 layer, FR-4, components on TOP, copper on BOTTOM, solder mask on bottom.**

---

## 1. Design philosophy for this process

Design to **nominal with margin**, not to the shop's absolute worst case.

Their stated hole tolerance is ±0.3 mm. Taken literally, a 1.0 mm hole could arrive at
0.7 mm and no 0.1″ header would fit anything. But their own note — *"if a specific drill
bit is unavailable, we'll use the next larger size"* — tells you the real variance is
**bit substitution upward**, not random error in both directions. So: size holes so that
the *next larger bit still works*, and give every pad enough annulus to survive it.

Design to the literal worst case and nothing at 2.54 mm pitch is manufacturable at all.

---

## 2. Rule table — enter these into EasyEDA Pro

| Rule | Value | Shop minimum | Why the margin |
|---|---|---|---|
| Signal trace width | **0.6 mm** | 0.5 mm | 20% over minimum |
| Power / rail trace | **1.5 mm** | — | Current + pad-lift resistance |
| Servo power run | **2.5 mm** | — | ~3.5 A at 1 oz |
| Clearance (all) | **0.6 mm** | 0.5 mm | |
| Trace to board edge | **1.0 mm** | 0.5 mm | Outline tolerance is ±1 mm |
| Silk text height | **2.2 mm** | 2.03 mm (80 mil) | Arial Bold |

### Drill and pad table

| Part | Drill | Pad Ø | Nominal annulus |
|---|---|---|---|
| 0.1″ header (0.64 mm sq pin, 0.91 mm diagonal) | **1.0 mm** | **2.0 mm** | 0.50 mm |
| JST-XH 2.5 mm | **1.0 mm** | **1.9 mm** | 0.45 mm |
| Screw terminal 5.08 mm | **1.2 mm** | **2.5 mm** | 0.65 mm |
| Jumper wire end | **0.9 mm** | **1.8 mm** | 0.45 mm |
| M3 mounting hole | **3.57 mm** (9/64″) | — | see below |

**Mounting holes:** 3.18 mm (1/8″) is tempting but its worst case is 2.88 mm, which will
not pass an M3 screw. **3.57 mm (9/64″)** worst-cases to 3.27 mm and always clears. Both
bits are on their list.

### JST-PH is excluded

2.0 mm pitch → max pad 1.5 mm against a 1.0 mm drill = 0.25 mm annulus, on a board with
**no plated through-holes**. That pad will lift. **Buy XH only** (Decision #27). One
pitch, one crimp tool, and no two connectors on the robot that can be cross-plugged.

---

## 3. The constraint that shapes the whole layout

**No trace can pass between two adjacent connector pins.**

```
0.1" header:   2.54 mm pitch − 2.0 mm pad  = 0.54 mm gap available
One trace needs: 0.6 clearance + 0.6 trace + 0.6 clearance = 1.8 mm

                          0.54  <<  1.8      ✗
```

JST-XH is the same story (0.6 mm gap). So **every net routes around every connector,
never through a header field.**

Consequences:

1. **Placement is the entire design problem.** Once modules are placed, the routing is
   nearly determined. Spend your time on placement.
2. **Orient every module so its pins face the thing they connect to.** A module rotated
   180° can add five jumpers on its own.
3. **Routing channel pitch is 1.2 mm** (0.6 trace + 0.6 clearance). Budget board area
   accordingly — this is ~4× the density of a JLCPCB 6/6 mil board.

---

## 4. Jumper wire strategy

With no vias, every crossing becomes an insulated wire link on the **top** side, landing
in two drilled holes with bottom-side pads.

- **Target: ≤15 jumpers on Board A, ≤5 on Board B.** If you exceed that, the placement
  is wrong — move modules, don't add wires.
- Use **solid-core 22 AWG insulated** wire, not bare. Bare links short against module
  bodies sitting on top of them.
- Give every jumper a **silkscreen outline and a `JP` designator**. You will rebuild
  this board at least once; undocumented jumpers are how a working board becomes an
  unreproducible one — and Rubric Criterion 5 scores reproducibility directly.
- **Never jumper a power rail.** Route power as copper. A jumper carrying servo or
  motor current is a fire, not a glitch.
- Record the final count in the journal. "We got it to N jumpers by doing X" is exactly
  the iteration evidence Rubric Criterion 4 pays for.

---

## 5. Ground on a single layer

There is no ground plane. You get a **ground pour on the one copper layer**, which is
strictly worse and must be drawn deliberately.

1. Route all **signals first**.
2. Pour ground over everything remaining, bottom layer.
3. **Check the pour is actually continuous.** On a single layer, signal traces cut the
   pour into islands. Every island that isn't connected back to the star is a floating
   copper flag — an antenna, not a ground. Stitch islands with jumpers if you must.
4. **One star point** (`ELECTRICAL.md` §2). Motor, servo and logic grounds meet there
   and nowhere else.
5. Keep the ToF/I²C cable ground return away from the servo power run.

This is the weakest part of the design and you should expect to iterate on it after
the first mat tests. Note that honestly in the journal — acknowledged limitations score
better than pretending a 1-layer board has good EMI behaviour.

---

## 6. Board outline and mechanics

- **Rectangular only** (their constraint). No cutouts, no rounded corners.
- Outline tolerance **±1 mm** — so **the board cannot be located by its edges.**
  Locate the stack by **mounting holes**, which are drill-position accurate. This is
  Decision #10 (locate by geometry) applied to the PCB.
- Use **3 mounting holes minimum**, at identical coordinates on both boards so the stack
  aligns. Three, not four — three always sits flat.
- Board B (lower) and Board A (upper) on **M3 standoffs**. Height must clear the tallest
  component on Board B plus the JST cable bend radius.
- Keep the Black Pill's **USB edge overhanging** the outline for flashing access.
- Minimum board size is 1 × 1 inch; maximum 10 × 8 inch. Both boards land well inside.

> ⚠️ **Board A vs the chassis plate.** `BOM.md` records an 80 × 130 mm printed plate.
> Estimated Board A is ~100 × 80 mm at these rules — it fits if you orient it 80 mm
> across the plate width. Verify in Fusion **before** ordering, not after.

---

## 7. Silkscreen — it is documentation

Top silk is the only layer a human reads, and it is free. Include:

- Designator **and function** on every connector: `J4 SERVO`, `J7 IMU`, `J2 ENC`.
- **Pin 1 marked** on every connector, plus pin-1 signal name.
- Polarity on every electrolytic, orientation arrow on every module.
- Board name, revision, date: `BLUEPRINT MAIN v1.0 2026-07`.
- Every jumper outlined with a `JP` number.

Text is ≥2.2 mm Arial Bold, which is large — lay it out as you place, not at the end,
or it will not fit.

---

## 8. EasyEDA Pro → PDF export (the shop takes PDF, not Gerber)

Their requirement for a single-layer board with solder mask:

| File | Content | Mirrored? |
|---|---|---|
| Top Silk | Component-side silkscreen | No |
| Bottom Copper | The copper layer | **YES — flip horizontally** |
| Bottom Resist | Solder mask openings | **YES — flip horizontally** |

Zip all three and submit.

**Procedure:**

1. Run **DRC** with the §2 rules loaded. Zero violations before you export anything.
2. `File → Export → PDF`.
3. Export each layer as a **separate PDF**, one layer selected per file.
4. **Scale = 1:1.** No "fit to page", no "shrink to printable area". This is the single
   most common way a board arrives wrong.
5. Set **Mirror** on Bottom Copper and Bottom Resist.
6. Choose **black-and-white / monochrome**, not greyscale. Anti-aliased grey edges can
   be misinterpreted by their imaging step.
7. Include the board outline on every sheet so they can register the layers.

**Verify before sending — this takes five minutes and has saved entire board runs:**

- Print all three PDFs on paper at 100%.
- Measure a known dimension with calipers — the 2.54 mm header pitch across 10 pins
  should read **25.4 mm**. If it doesn't, the scale is wrong.
- Lay the printed bottom-copper sheet under a real 0.1″ header and a real JST-XH
  connector. Pins should land in pads.
- Confirm the mirrored sheets are actually mirrored: text on bottom copper should read
  **backwards** on the printout.

---

## 9. Test coupon — do this before the real boards

A 1 × 1 inch scrap board, submitted first. It validates every number in §2 against what
the shop *actually delivers* rather than what they advertise.

Put on it:

| Feature | Tests |
|---|---|
| 1× 8-pin 0.1″ header footprint | Do real pins fit? Is the annulus intact? |
| 1× JST-XH 4-pin footprint | Same, at 2.5 mm pitch |
| 1× M3 hole at 3.57 mm | Does an M3 screw pass? |
| Trace/gap ladder at 0.5 / 0.6 / 0.8 / 1.0 mm | Where does their process actually break? |
| 2 mm and 3 mm silk text | Is 2.2 mm really legible? |
| A 2.5 mm power trace | Width fidelity |
| Solder mask over half the traces | Registration accuracy |

Then **solder to it and pull the pads off with pliers.** You need to know how much force
lifts a pad on this process before you find out via an intermittent fault in September.

Cost: one board minimum order. Against the risk of etching two full boards to wrong
assumptions eight weeks before the competition, this is the cheapest insurance available.

---

## 10. Assembly rules (Decision #11 / #12 carried onto the PCB)

- **No Dupont anywhere.** JST-XH crimps or screw terminals only.
- **Strain relief on every cable** leaving a board — a zip-tie anchor hole next to each
  connector costs one drill hit. On a board with no plated holes, cable strain is the
  #1 pad-lift cause.
- **Twist the encoder A/B pair.** Twist the I²C SCL/SDA pair in the inter-board cable.
- Route the inter-board cable and the encoder cable **away from the motor leads and
  the servo run**.
- Threadlocker or nail polish on standoff threads (Decision #10).
- Solder every module header — do not rely on friction fit.

---

## 11. Checkpoint reviews

Per the agreed workflow, send at these three points:

| Checkpoint | Send | Reviewed for |
|---|---|---|
| **1 — Schematic** | PDF export of both sheets | Netlist vs `ELECTRICAL.md`, pin map vs `electrical/README.md`, missing decoupling, pull-ups, star ground |
| **2 — Placement** | Screenshot, modules placed, no routing | Jumper count implied by placement, module orientation, servo/motor run separation, board size vs chassis |
| **3 — Routing + DRC** | DRC report + the three export PDFs | Rule violations, ground pour continuity and islands, trace widths on power, mirror and 1:1 scale |

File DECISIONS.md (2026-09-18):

# DECISIONS — locked, with reasons

One line per locked decision + the REASON. Source of truth; append as things lock.

> **Note (2026-09-18):** the September rebuild changed several things without new numbered
> entries: steering is now an **Ackermann linkage** (supersedes #15's parallelogram and #5's
> rejection), the servo is a **JX PS-1171MG** digital servo (the MG996R analog 50 Hz notes no
> longer apply), the race IMU is a **BNO085** (closes #24's procurement flag), and the carrier
> was re-pinned. These are recorded in [`docs/timeline.md`](docs/timeline.md#2-rebuild-for-the-asia-pacific-championship-hyderabad-india)
> and should get their own dated entries here.

1. **Nav = gyro heading-hold, 90° turns terminated by IMU, re-reference heading at every corner** — turn ends on measured heading not steering angle, so tyre slip can't corrupt it; re-referencing bounds gyro drift. Mirrors the previous BD national winner (fastest + smoothest).

   - **AMENDED — 2026-07-26 (as-built).** Turn trigger is now the **TCS34725 floor colour sensor**, not the front wall distance. Corner lines are 20 mm thick (rule 13.9); at the as-built 0.70 m/s a line is under the sensor for 28.6 ms, giving ~11 samples at 2.4 ms integration. Front ToF is DEMOTED to confirmation/anti-collision only. Two additions are mandatory and were not in the original decision: (a) **event lockout** — each corner is marked by an orange line AND a blue line, so a naive "saw colour" trigger fires ~24 times over 3 laps instead of 12; all colour input must be ignored from the moment a turn starts until the turn completes and the car has driven clear; (b) **direction decode** — the driving direction is drawn randomly before each round (rule 9.3), so the ORDER of the first line pair (orange-then-blue vs blue-then-orange) sets the turn direction for all 12 turns. Without (b), 50% of runs steer the wrong way. The IMU-terminated 90° turn and per-corner heading re-reference are UNCHANGED and remain the core of the decision.

2. **Compute split: Open round = STM32 only; Obstacle round adds Pi + fisheye for pillar colour only; link = checksummed UART, never inter-board I2C** — keeps the driving loop fully deterministic with no Pi/WiFi jitter; I2C between boards is a known glitch source, UART with checksum is robust.

3. **STM32 over ESP32** — clean 12-bit ADC for analog Sharp IR (ESP32 ADC noise becomes distance randomness), hardware quadrature encoder timers, deterministic timing with no WiFi stack stealing cycles.

4. **Steering = single central pivot, bell-crank, bearing-supported shaft, AS5600 encoder on the shaft, servo commanded in microseconds** — bell-crank is the documented RC standard (turntable swings wheels fore/aft + long lever arm for bump loads); AS5600 closes the loop on true wheel angle and kills servo backlash; µs commanding avoids the ~10 µs/deg quantisation of degree commands.
   - **EVIDENCE 2026-07-12 (single central pivot CONFIRMED for parking):** a kinematic slop Monte-Carlo + a pymunk dynamic-friction sim (`src/sim/`, `journal/steering-study-2026-07-12.md`) compared single central pivot (turntable) vs Ackermann bell-crank vs parallel bell-crank for the parallel park. Findings: (a) equal-angle scrub is 8° at full lock kinematically BUT dynamically cheap at parking speed (surface sensitivity ~equal, TT 2.7 mm vs ACK 2.9 mm); (b) single pivot is ~3× more robust to build slop (0.42 vs 1.25 mm run-to-run @0.5° joint slop) because its one bearinged joint is exactly what the AS5600 measures; (c) 1 joint vs 5 — decisive for a novice assembler. Parallel bell-crank is strictly dominated → dropped. Ackermann only pays off at higher speed (untested) or with downstream joints built <0.3°. Net: single central pivot stays locked for v1.

   - **SUPERSEDED — 2026-07-26 (as-built: parallelogram steering, AS5600 dropped).** The car was built with **parallelogram (equal-angle, tie-bar) steering**, not a single central pivot, and without the AS5600. Reason, in the team's words: a central pivot turns the whole front beam about one axis, so during a turn one front wheel swings forward and the other swings back — the car's effective length grows exactly when clearance matters most. Quantified: each front wheel translates fore/aft by **(track/2)·sin δ**. At the as-built track = 105 mm and lock δ = 35°, that is **±30.1 mm per wheel**, which consumes **36% of the 82.5 mm total parking slack** (bay = 1.5 × 165 mm car = 247.5 mm) for zero navigational benefit, against a rule where touching a magenta parking-lot limitation scores 0 parking points (rule 9.24.7).
     **Why the simulation did not catch this:** `src/sim/steering_study.py` scored candidates on kinematic scrub, parking accuracy and slop robustness. It **never modelled the swept envelope of the vehicle body during the turn**. That missing objective term is the entire reason it ranked parallel bell-crank as "strictly dominated". The build found the term the model was missing. This is recorded as an iteration, not as an error: the original study and its conclusion are preserved unedited in `journal/steering-study-2026-07-12.md`.
     **Accepted costs, on the record:** (a) 4+ linkage joints instead of 1, against `DECISIONS.md` #10's novice-assembler principle; (b) no AS5600, therefore **steering is fully open-loop** — commanded angle ≠ actual angle, and the error will grow as joints wear; (c) equal-angle steering, so tyre scrub is UNCHANGED from the turntable (parallelogram is not Ackermann); (d) **turn radius R is nominal, not measured.**
     **Why it is still sound:** the loop is closed on *vehicle heading* by the IMU, not on steering angle (Decision #1). Steering therefore only has to be monotonic and repeatable, not accurate. This is the same argument that lets Decision #1 terminate turns on measured heading rather than steering angle. The residual exposure is parallel parking, which needs a predictable arc — see Decision #21.

5. **Ackermann rejected for v1** — 4–6 slop-prone joints, worst choice for a novice assembler; analyse the trade-off in the journal for rubric points instead of building it.

6. **"Straight" found by motion, not by eye (sweep µs, drive ~3 m, bisect gyro yaw-rate to zero → CENTER_US)** — no car is mechanically straight; gyro heading-hold finds the true straight, removing a source of randomness.

7. **Sensors = analog Sharp IR (calibrated, median-filtered, mounted out of the fold-back zone) and/or front sonar; ToF rejected; LIDAR deferred** — walls are big flat perpendicular reflectors ideal for IR/sonar; ToF randomly false-detects the floor; LIDAR is heavy/tall and forces Pi 5 + Linux jitter against the determinism goal (design upper deck to accept it later).
   - **REVISION 2026-07-12 (team override):** primary distance = **ToF VL53L1X ×5** (already on hand). This reverses the "ToF rejected" clause above. Reason: parts owned; VL53L1X is far better than the generic ToF the rejection referred to. RISK acknowledged (false floor returns on a low car) → mitigate by above-grazing-angle mount, tight ROI window, min-range + floor gating, median filter, and VALIDATE on the real mat. Sharp IR / sonar demoted to documented fallback (Sharp bought only if ToF fails on the mat). Original rejection reasoning kept above so the trade-off is on record for the journal.

   - **CORRECTED — 2026-07-26 (part is VL53L0X, not VL53L1X).** The sensors on hand are **VL53L0X ×5**, not VL53L1X. This invalidates the primary mitigation assumed in the 2026-07-12 revision: **the VL53L0X has no programmable ROI.** Its field of view is fixed at ~25° and cannot be narrowed in firmware. The mitigation is therefore MECHANICAL — see Decision #18.
     **Why this matters more than it looks:** the mat is white (rule 13.2) and both exterior and interior walls are black on every visible face (rules 13.4, 13.6). The false target (floor) therefore reflects NIR *better* than the true target (wall). A naive closest-return read locks onto the floor. This is the concrete, quantified form of the original "ToF randomly false-detects the floor" objection that this decision overrode, and it is now the single highest-risk item in the build. The Sharp GP2Y0A21 fallback in `BOM.md` must have a confirmed lead time before the mitigation is validated on the mat.

8. **Sensors + camera mount to the FIXED chassis, never the pivoting steering beam** — readings must not swing when the steering turns.

9. **Ball bearings on every axle AND the steering pivot** — plastic-on-shaft wears in and grows slop mid-competition; bearings keep geometry constant.

10. **Locate every part by GEOMETRY (shoulders, slots, captured screws); glue is backup only** — a loose joint must still be unable to shift, because the assembler is a novice and joints sometimes come loose.

11. **No Dupont jumpers / no breadboard on the robot — solder or JST/screw terminals with strain relief** — jumpers/breadboards are the #1 source of "random" glitches.

12. **Separate motor + logic power domains joined at ONE star ground; bulk cap 470–1000 µF on motor rail, 0.1 µF near MCU, 0.1 µF across motor terminals; threadlocker on every thread; twisted encoder leads with pull-ups** — motor brown-out causes random MCU resets and EMI causes random glitches; these kill both.

13. **Deliverable of the design phase = a justified, print-ready v1 — NOT a finished car** — "competition-level" is earned by testing and iterating on a real mat in Sept–Oct, not in chat.

14. **Drivetrain = SOLID rear axle (both rear wheels locked to one shaft); NO open differential** — quantified in `src/sim/rear_axle_scrub.py` / `media/steering/6_rear_axle.png`. A solid axle scrubs 94 mm per rear wheel per 90° corner (= track/2 × angle, independent of radius), BUT distance odometry is **unbiased (0.00 mm) for both a solid axle and a diff** — the encoder sits at the mean-wheel-speed (axle / diff carrier) so scrub cancels; the diff fixes nothing there. An open diff instead ADDS: gear-backlash odometry jitter (±0.17–0.70 mm per reversal) and, on the low-grip mat, a torque-bias one-wheel-spin failure = a randomness event that violates the no-randomness spec, plus more parts/slop for a novice assembler. Net: the diff's only real benefit (no scrub) has no scored payoff for a low-speed, gyro-navigated, sensor-parked car, so the simple solid axle wins. (Revisit only if the car ever becomes fast + grippy + high-cornering.)

   - **CONFIRMED as-built — 2026-07-26.** Built as specified: solid rear axle, no differential, driven through a **5:1 gear reduction** meshed to the rear wheels. The 5:1 was not in the original decision and is the single highest-value change in the build: it takes the 25GA from 1331 RPM / 2.79 m/s (uncontrollable) to **266 RPM / 0.70 m/s**, and multiplies encoder resolution by 5. It also makes the TCS line-detection timing comfortable (28.6 ms dwell on a 20 mm line vs 7.2 ms ungeared).

15. **Steering = parallelogram (equal-angle tie-bar), lock ±35°, open-loop** — as built. Full rationale, quantified swept-envelope argument and accepted costs are in the Decision #4 supersession block above. Measured lock angle 35°; with the wheelbase this gives R = wheelbase ÷ tan 35°. Track 105 mm centre-to-centre, 115 mm wheel-extreme to wheel-extreme.
    - **Wheelbase measured 2026-07-28: 110 mm.** Gives **R = 110 ÷ tan 35° = 157 mm** and R/L = 0.95. Ceiling was 117 mm from the 165 mm body length, so 110 mm sits comfortably inside it. 🚩 Note for anyone reading later: **105 mm is the TRACK** (lateral, wheel centre to wheel centre); the wheelbase is longitudinal, front axle centre to rear axle centre. The two were confused more than once during design.
    - **CAD GROUND TRUTH (2026-09-15):** The final CAD assembly in Autodesk Fusion 360 confirms the exact longitudinal wheelbase as **136.14 mm** (dimensioned at 136.139 mm axle-to-axle, 136.126 mm rim-to-rim), extreme track width as **114.24 mm** (114.244 mm), and kingpin pivot span as **80.59 mm** (80.589 mm). Steering knuckles are engineered with true 100% Ackermann geometry at **107.0° / 73.0°** ($17.0^\circ$ inward inclination), precisely converging at the rear axle center ($\arctan(40.295 / 136.14) = 16.49^\circ \approx 16.5^\circ$). Gives $R = 136.14 / \tan(35^\circ) = \mathbf{194.4\text{ mm}}$.
    - **Lock ±35° is FINAL** (2026-07-28). Decision #28 briefly raised it to ±40° and has been withdrawn — see #28.

16. **Steering loop is closed on IMU heading, not on steering angle** — the AS5600 was dropped with the central pivot, so there is no steering-angle feedback. This is acceptable because Decision #1 already terminates turns on measured heading; steering only needs to be monotonic and repeatable. The cost is that turn radius is nominal rather than measured, which is harmless for the 12 open-round corners and is the binding risk for parallel parking (Decision #21).

17. **Turn trigger = TCS34725 floor colour, with hard event lockout and first-pair direction decode** — see the Decision #1 amendment. Front ToF demoted to confirmation. TCS integration time ≤10 ms; **no median filter on the colour sensor** — a median filter smears a 28.6 ms line event away. Use single-sample edge detection with hysteresis.

18. **VL53L0X floor rejection is MECHANICAL: a printed collimator snout, 2.5 mm tall × 10 mm wide × 20 mm deep, plus a +2° upward mounting wedge** — the L0X has no ROI (Decision #7 correction), so firmware cannot narrow the beam. The snout narrows the *vertical* half-angle to atan(1.25/20) = **3.58°** while leaving horizontal FoV intact. The slot must be WIDE, not round: the L0X emitter and receiver apertures are ~2.5 mm apart and a round hole vignettes the receiver.
    **The wedge is not optional.** Front wheels are 46 mm and rear wheels are 50 mm, so the chassis sits nose-down by atan(2/wheelbase) ≈ **1.0–1.1°**, and every chassis-mounted sensor inherits it — aimed at the floor. Net effective half-angle θ_eff = 3.58° + rake − wedge.
    Floor first-return `d_floor = h / tan(θ_eff)`, against a side-wall distance of (1000 − 115)/2 = **442.5 mm**:
    | Wedge | θ_eff | d_floor @ h=40 mm | Margin |
    |---|---|---|---|
    | 0° | 4.67° | 490 mm | +47 mm ✗ |
    | +1.1° (cancel rake only) | 3.58° | 640 mm | +197 mm |
    | **+2.0°** | **2.67°** | **859 mm** | **+416 mm ✓** |
    Beam axis at 442.5 mm is then 47 mm high — far below the 100 mm wall top (rules 13.3, 13.5), so nothing is lost. Margin improves as car height grows (see `electrical/collimator.py`). **Offset calibration must be re-run after the snout is fitted** — the hood changes crosstalk.

19. **ToF layout = F / FL30° / FR30° / L90° / R90°, with a deliberate split of duties** — L90/R90 do open-corridor lane centring (442.5 mm lateral, well inside d_floor). FL30/FR30 do *obstacle-corridor* centring when threading a pillar-to-wall gap, where slant range = gap ÷ sin 30° = 2 × gap: a 150 mm gap reads at 300 mm, a 350 mm gap at 700 mm — both comfortably inside d_floor. The 30° pair degrades exactly when the gap is wide, which is when L90/R90 take over. **Known risk to bench-test:** at 30° off-axis the beam strikes the wall at 60° from normal, so Lambertian return falls by cos 60° = 0.5 on a surface that is already black. Verify signal rate against black MDF at 60° incidence at 300 mm and 700 mm before committing mount angles.

20. **Bus split: 5× VL53L0X alone on I²C1 (XSHUT-reassigned to 0x30–0x34); TCS34725 alone on I²C2; MPU9250 on SPI1** — the VL53L0X and the TCS34725 share factory address **0x29**, and the TCS has neither a shutdown pin nor an address strap. During ToF enumeration each sensor wakes at 0x29, so every enumeration write would also hit the colour sensor. Splitting the buses removes the collision and additionally isolates the turn trigger — the single most critical sensor in the open round — from any ToF cable fault. Moving the MPU9250 to SPI (it is SPI-capable) leaves the TCS as the sole device on I²C2.
    **XSHUT is open-drain, no internal pull-up** — the L0X die is 2.8 V logic; pull low to shut down, release to Hi-Z and let the breakout's own pull-up set the rail. Safe on 2.8 V-native and 3.3 V-shifted boards alike.
    **Reassigned addresses are volatile and are lost on any brownout**, so enumeration re-runs on every reset: all XSHUT low → 10 ms → release ch0, 2 ms, write 0x30 → repeat to 0x34 → verify → **skip any failure and continue**, never stall → report result on the status LED before entering ARMED.
    **Do not use the MPU9250 magnetometer.** A BTS7960 switching amps on a 115 mm-wide chassis will corrupt it. Gyro-Z only, DLPF ≈ 41 Hz, polled on a fixed 1 kHz timer tick for a constant integration timestep.

21. **Parallel parking arcs are closed on IMU yaw, not on odometry or steering angle** — steering is open-loop (Decision #16), so the nominal R cannot be trusted to produce a repeatable arc. Closing each park arc on measured yaw uses the sensor already trusted for the 12 corners and removes the dependence on R entirely. Feasibility against the two magenta limiters must be proven by `src/sim/park_feasibility.py` before mat testing; touching a limiter is 0 parking points (rule 9.24.7).
    - **RESULT 2026-07-26 — the two-arc park FAILS and the manoeuvre is changed.** The solver sweeps the parked longitudinal position (the only free variable at fixed lock) and finds the front-outer corner strikes the entry limiter by **25.6 mm** at the as-built 35 deg lock. R/L = 0.95; a symmetric two-arc needs roughly **R/L <= 0.7**. Raising lock to 45 deg reaches R/L = 0.67 and clears by ~0.1 mm — no usable margin, and worthless with open-loop steering. **The problem is scale-invariant:** bay = 1.5 x car length always, so slack = 0.5 x car length always; shortening the car cannot help. **Primary parking manoeuvre is therefore a MULTI-POINT (3+) SHUFFLE closed on IMU yaw, not a two-arc.** This supersedes "Park manoeuvre: reverse two-arc" as carried in SPECSHEET since 2026-07-12.

22. **Motor driver = BTS7960, accepted with its costs stated** — on hand, and it will work. It is ~20× oversized for a 25GA (43 A rating), weighs ~66 g with heatsink against a ~450 g target, and occupies 50 × 50 × 27 mm on an 80 × 130 mm plate alongside a Pi 4B. Its real functional cost is poor resolution at the bottom of the range, exactly where parking lives (~0.1 m/s ≈ 14% duty). **Closed-loop speed control on the encoder is therefore mandatory, not optional.** At 0.175 mm/count there is ample feedback to do it. A TB6612FNG would be a better match on every axis except headroom; revisit if low-speed control proves erratic on the mat.
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

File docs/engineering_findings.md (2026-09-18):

# Engineering Findings & Iterations — What Broke and What We Learned

> This document records the empirical discoveries, analytical failure proofs, and hardware design revisions made by **Team Blueprint** throughout the development of our WRO Future Engineers vehicle.
> For the high-level system overview, return to the **[Master README](../README.md)**.

---

## 1. Floor IR Crosstalk and Optical Collimation

<p align="center">
  ToF cone hitting the floor, before and after collimation
</p>

### The Problem
* **Optical Environment**: The WRO Future Engineers mat is high-reflectance white vinyl (Rule 13.2), while perimeter and interior corridor walls are low-reflectance matte black MDF (Rules 13.4, 13.6).
* **Optical Spread**: The VL53L0X has a fixed, uncollimated Field of View of $\approx 25^\circ$ (no programmable ROI). The VL53L1X used by the obstacle program has a similar default FoV.
* **Chassis Rake**: Due to front wheel diameter ($46\text{ mm}$) and rear wheel diameter ($50\text{ mm}$), the chassis sits with a natural nose-down rake:
  $$\text{rake} = \arctan\left(\frac{(50 - 46)/2}{L}\right) = \arctan\left(\frac{2}{136.14}\right) \approx 0.84^\circ\text{ nose-down}$$
  (The July analysis used the then-measured $L = 110\text{ mm}$, giving $1.04^\circ$.)
* **Consequence**: The bottom of the sensor's infrared cone struck the reflective white floor at just $166\text{ mm}$. Because the white mat returned a vastly higher photon count than the distant black wall, the sensor locked onto the floor, reporting phantom walls and triggering false corner turns.
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

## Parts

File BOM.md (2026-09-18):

# BOM — Bill of Materials

**As-built, updated 2026-09-18** (originally 2026-07-26; supersedes the 2026-07-12 speculative BOM).
⚠️ Source, lead time and price are still **Open Question #3** — fill from a real
inventory check + Daraz/RoboticsBD lookup. TBD = not yet confirmed.

## Locked / on hand

| Part | Spec | Status | Note |
|---|---|---|---|
| Drive motor | 25GA gearmotor, 1331 RPM, encoder on motor | **On hand** | Measured scale: 14.853 ticks/cm (current car) |
| Gear reduction | **5:1**, meshed to solid rear axle | **Built** | → 266 RPM, 0.70 m/s theoretical |
| Rear axle | Solid, no differential | **Built** | Decision #14 |
| Steering | **Ackermann linkage** (107° / 73° arms), lock **±35°** | **Built** | Replaced the parallelogram of Decision #15 in September |
| **I²C mux** | **TCA9548A / PCA9548A module** @ 0x70 | **On hand** | Decision #23 — replaces XSHUT addressing, reverses #20 |
| Steering servo | **JX PS-1171MG** — digital, metal-gear, 17 g | **On hand** | Replaced the MG996R (analog, ~55 g) |
| MCU | **STM32F411CEU6** "Black Pill" | **On hand** | 26/28 usable pins allocated |
| Motor driver | **BTS7960** 43 A | **On hand** | Decision #22 — ~20× oversized, ~66 g, poor low-duty resolution |
| Distance | **VL53L0X** (Open fw: 1× front) and **VL53L1X** (Obstacle fw: left, right, front) | **On hand** | VL53L0X has no programmable ROI — Decision #7 correction; one sensor per mux channel |
| Floor colour | **TCS34725** | **On hand** | I²C 0x29, on its own mux channel |
| IMU | **BNO085**, SPI | **On hand** | Race IMU (Decision #24). Game rotation vector, no magnetometer |
| IMU — bench only | MPU6050, I²C, `WHO_AM_I` = 0x68 | On hand | No longer used |
| SBC (obstacle round only) | **Raspberry Pi 5, 8 GB** | **On hand** | Quad-core A76 @ 2.4 GHz; runs concurrent vision + LIDAR SLAM |
| LIDAR (obstacle round only) | **Slamtec RPLIDAR C1** | **On hand** | 360° DTOF, 12 m range, ~110 g; USB to Pi 5 (Decision #29) |
| Camera | **Fisheye 160° FoV** | **On hand** | Pillar colour detection + horizontal offset |
| Battery | **3S LiPo, 75C** | **On hand** | ⚠️ capacity/mAh still TBD |
| Buck (logic) | 5 V module | **On hand** | Feeds Board A logic + Board B |
| Wheels | Front **46 mm**, rear **50 mm**, printed | **Made** | 4 mm mismatch → 1.0–1.1° rake, corrected by ToF wedge |
| Chassis | Printed, 80 × 130 mm plate | **Built** | |

## Required, not yet sourced

| Part | Spec | Why mandatory |
|---|---|---|
| Master switch | SPST, **≥10 A**, panel mount | Rule 9.10 — exactly one switch may power the vehicle on |
| AMS1117-3.3 + 22 µF | Board B local 3.3 V regulator | ~250 mA sensor load; keeps it off the MCU rail |
| Start button | Momentary NO + 10 kΩ / 1 kΩ / 100 nF debounce | Rule 9.11 — separate from the power switch. ⚠️ Not yet wired/read on the current carrier (PB15 reserved) |
| BEC-S | **6.0 V, 3 A cont / 5 A peak** | Servo stall current must not sag the logic rail |
| BEC-L | **5.0 V, 2 A** | STM32 + 5× ToF + TCS + IMU ≈ 150 mA typ |
| BEC-C | **5.1 V, 5 A**, adjustable | Pi 5 + RPLIDAR C1; prevents low-voltage USB throttling (Decision #29) |
| Battery connector | XT30 | |
| Bulk caps | 1000 µF 25 V low-ESR (BTS7960 input), 470 µF (servo connector) | Brown-out prevention |
| Ceramics | 0.1 µF ×~15 — motor terminals ×1, terminal-to-can ×2, every IC VCC | EMI + decoupling |
| Encoder RC | 10 kΩ pull-ups ×2, 100 Ω + 1 nF ×2 | f_c ≈ 1.6 MHz vs 3995 Hz signal |
| I²C pull-ups | 2.2 kΩ ×4 (2 per bus) | 400 kHz noise margin |
| Series resistors | 220 Ω ×3 (servo signal, UART TX/RX) | Ringing suppression |
| Connectors | **JST-XH only** (2.5 mm) + crimp tool, 5.08 mm screw terminals | **No Dupont anywhere** (#11). **JST-PH dropped** — 2.0 mm pitch is not manufacturable at our fab (#27) |
| Ball bearings | Every axle + steering pivots | Decision #9 — bore/OD depends on shaft, lock shaft first |
| Fasteners | Nyloc nuts, threadlocker / nail polish | Decision #10 |
| **ToF collimator snouts** (one per ToF) | **2.5 × 10 × 20 mm slot + 2° wedge**, printed | **Decision #18 — the L0X has no ROI; this is the only floor mitigation** |

## Contingency — order decision pending a bench test

| Part | Trigger | Risk |
|---|---|---|
| Sharp GP2Y0A21 ×2–5 | If VL53L0X signal rate against **black MDF** is marginal at 442 mm (90° pair) or at 60° incidence (30° pair) | ⚠️ **Lead time still unrecorded.** This is the highest-risk unpriced item in the build — if the ToF mitigation fails on the mat and Sharp is 3 weeks out, there is no recovery path. |
| TB6612FNG | If BTS7960 low-duty control proves erratic | Decision #22 |

## Dropped

| Part | Reason |
|---|---|
| AS5600 | No central pivot to measure — steering is open-loop, closed on IMU heading (Decision #16) |
| ~~TCA9548A mux~~ | ~~XSHUT reassignment fits the pin budget (Decision #20)~~ — **REVERSED by #23.** A PCA9548A is now on hand and in use; XSHUT addressing is dropped instead. |
| MPU9250 | Not on hand. Superseded by MPU6050 (bench) + BNO085 (race) — Decision #24 |
| MG996R servo | Replaced by the JX PS-1171MG in the September rebuild |
| Parallelogram steering | Replaced by the Ackermann linkage in the September rebuild |
| **Inline fuse** | **Team decision #26 — accepted risk, not an oversight** |
| **JST-PH** | 2.0 mm pitch gives a 0.25 mm annulus at our fab, on a board with no plated holes — Decision #27 |
| XSHUT wiring ×5 | Unnecessary once each ToF has its own mux channel — Decision #23 |
| ~~LIDAR~~ | ~~Deferred~~ — **REVERSED by Decision #29.** Slamtec RPLIDAR C1 added for obstacle round. |

## Mass check
Electrical ≈ 3S LiPo 75 g + BTS7960 66 g + 3 BECs 35 g + harness 45 g + JX PS-1171MG 17 g
+ Pi 5 (with active cooler) ~60 g + RPLIDAR C1 ~110 g = **~408 g** before chassis/wheels/motor.
Total vehicle mass is estimated at **~540–580 g** (obstacle configuration; not yet weighed),
comfortably below the 1.5 kg WRO ceiling.

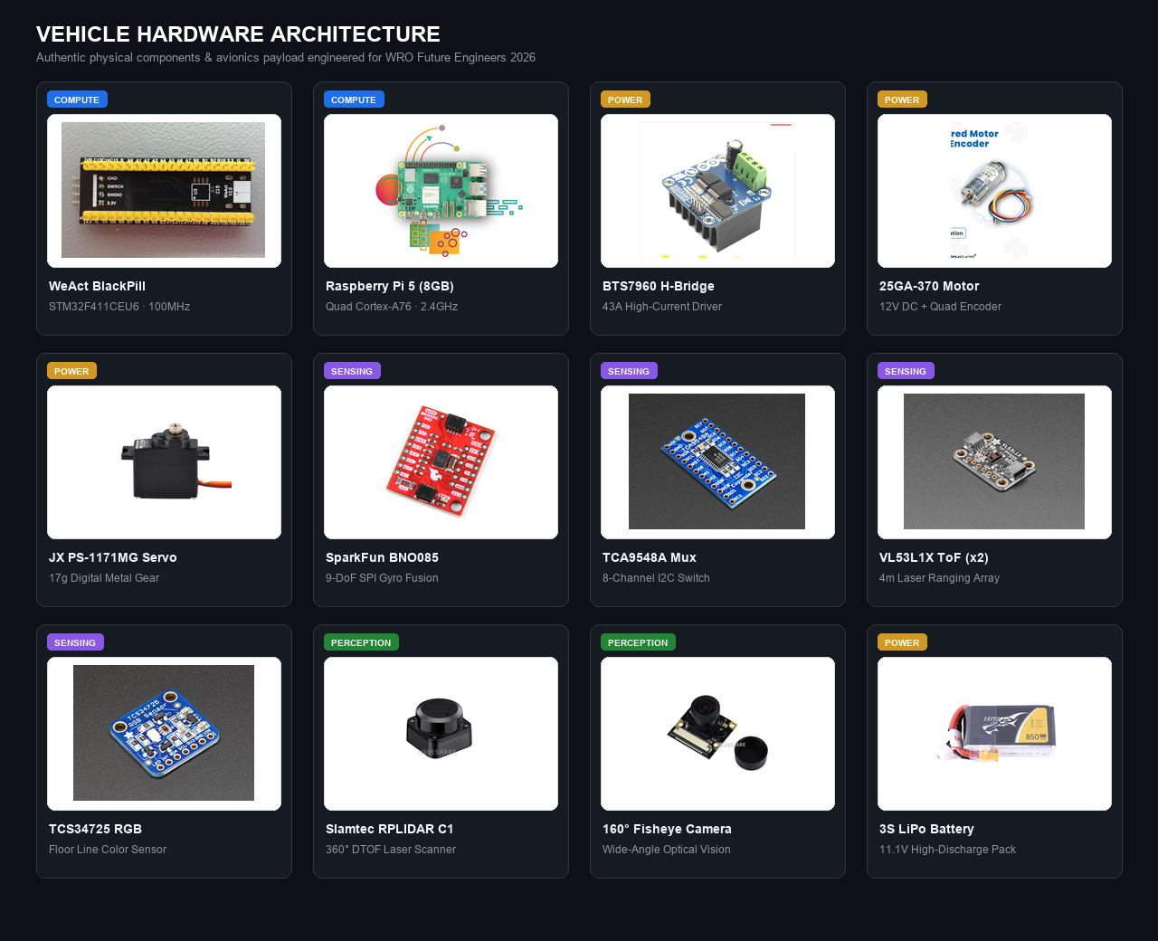
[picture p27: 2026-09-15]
media/components/hardware_components.png

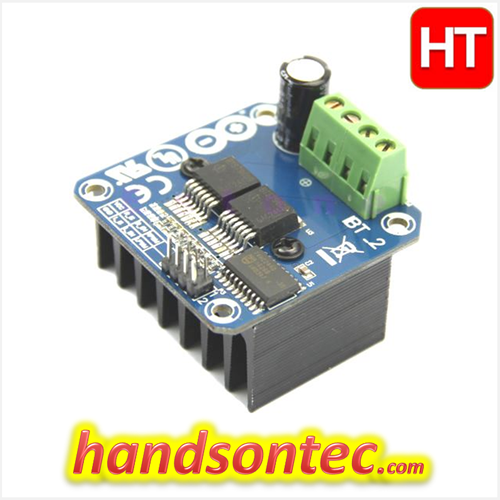
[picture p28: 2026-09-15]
media/components/bts7960.png

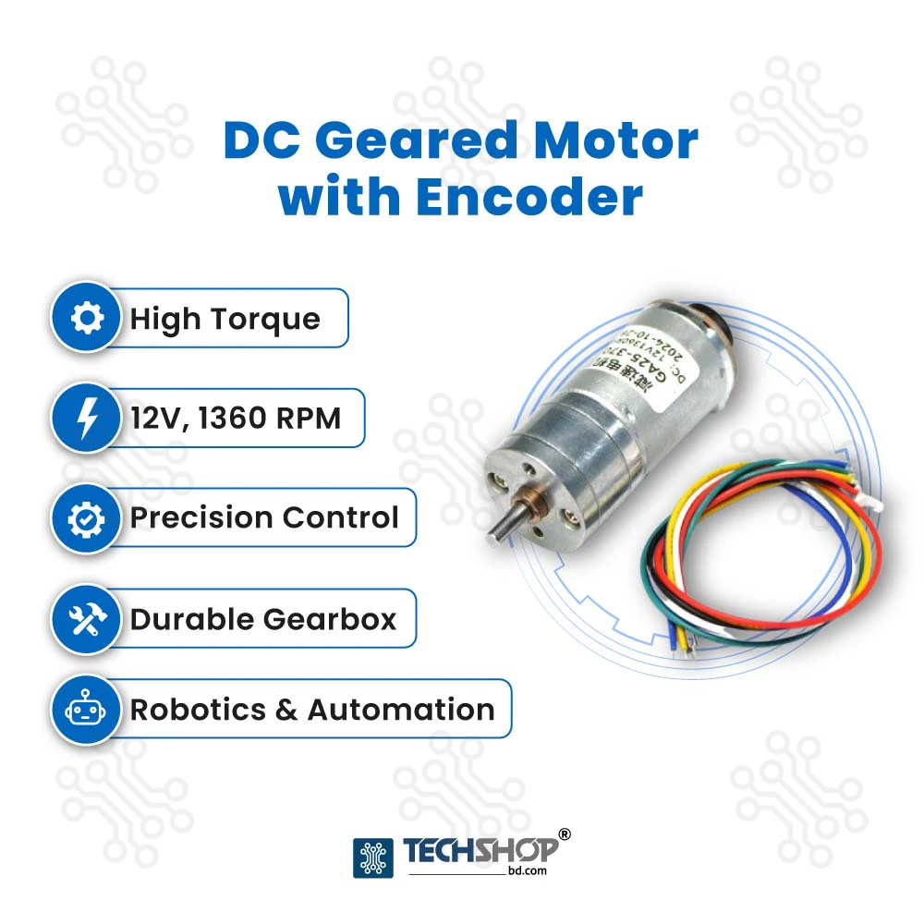
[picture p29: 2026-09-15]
media/components/motor_25ga.webp

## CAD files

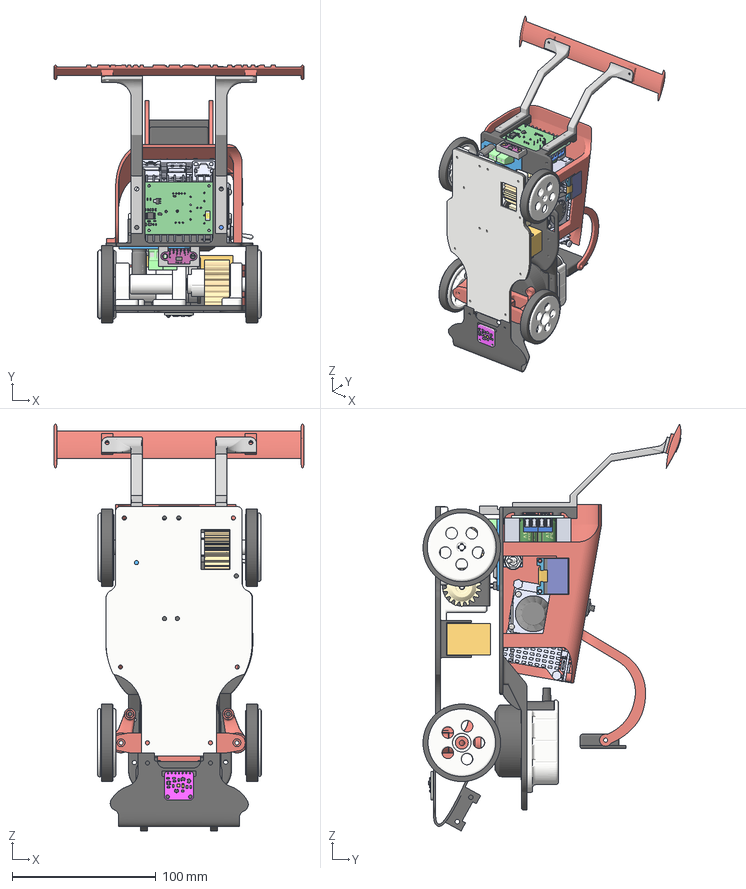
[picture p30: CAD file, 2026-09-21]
models/ASMB.3mf
174.0 x 179.5 x 283.4 mm
Base Plate
Center BR
Connector B22
Front Bumper
LEGO Gear BOX
Left BR
Left Bearing Mount
Left Front Tire
Left Front Wheel
Left Rare Tire
Left Rare Wheel New
Left Stearing Hand
Lego Shaft
LiDAR mount
Middle Plate
Midle Bearing and Motor mount
Motor Mount
RP Lider C1
Right BR
Right Bearing Mount
Right Front Tire
Right Front Wheel
Right Rare Tire
Right Rare Wheel
Right Stearing Hand
Top Plate

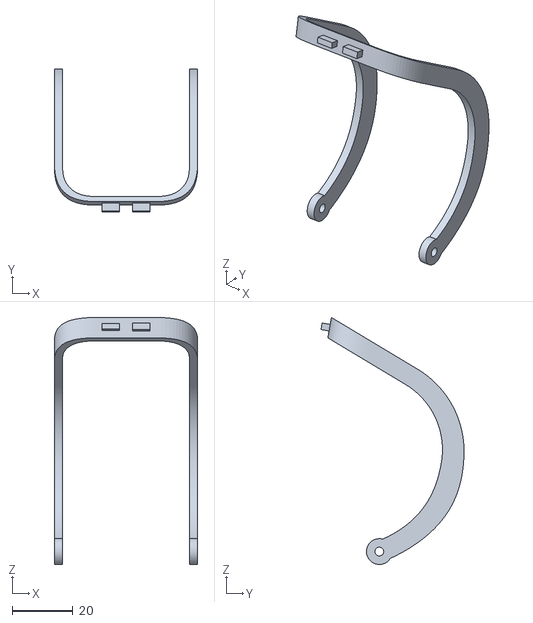
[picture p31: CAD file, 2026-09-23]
models/Camera Holder ras.stl
47.0 x 47.0 x 81.1

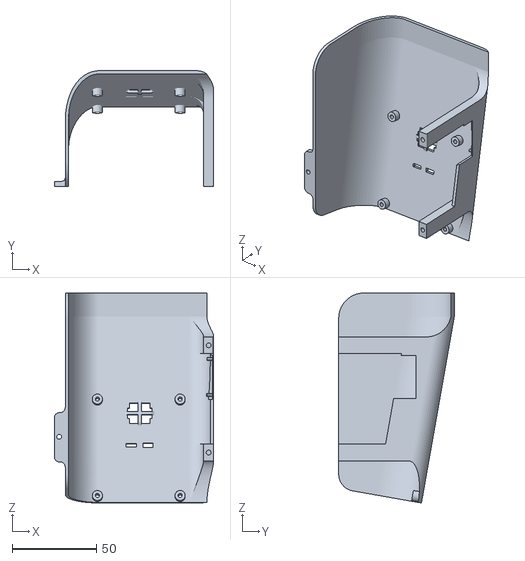
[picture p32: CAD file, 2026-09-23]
models/Top Plate.stl
94.4 x 68.5 x 124.4

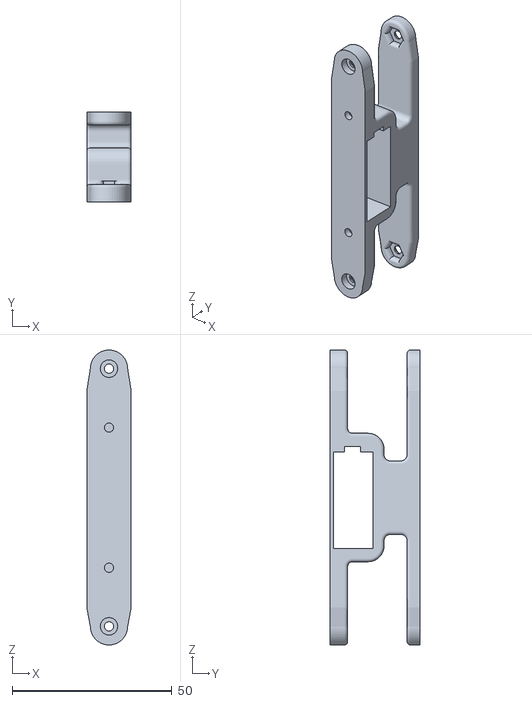
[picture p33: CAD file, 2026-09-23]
models/Stearing Holder .stl
13.9 x 28.1 x 92.4

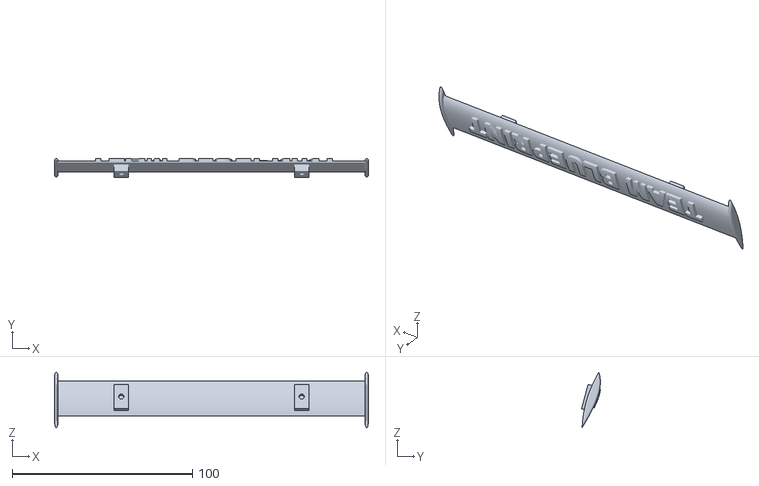
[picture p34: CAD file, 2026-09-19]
models/Tail .stl
174.0 x 10.5 x 30.8

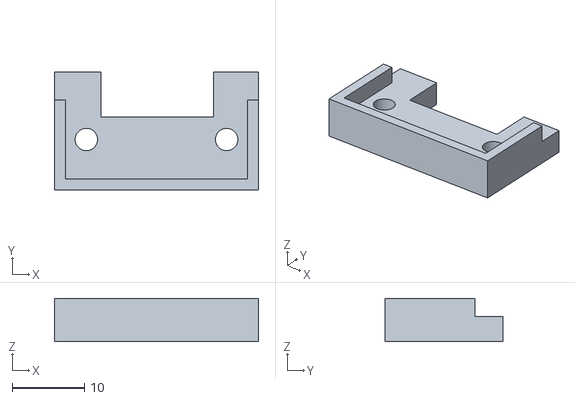
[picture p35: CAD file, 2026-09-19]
models/Back TOF.stl
28.2 x 16.2 x 6.00

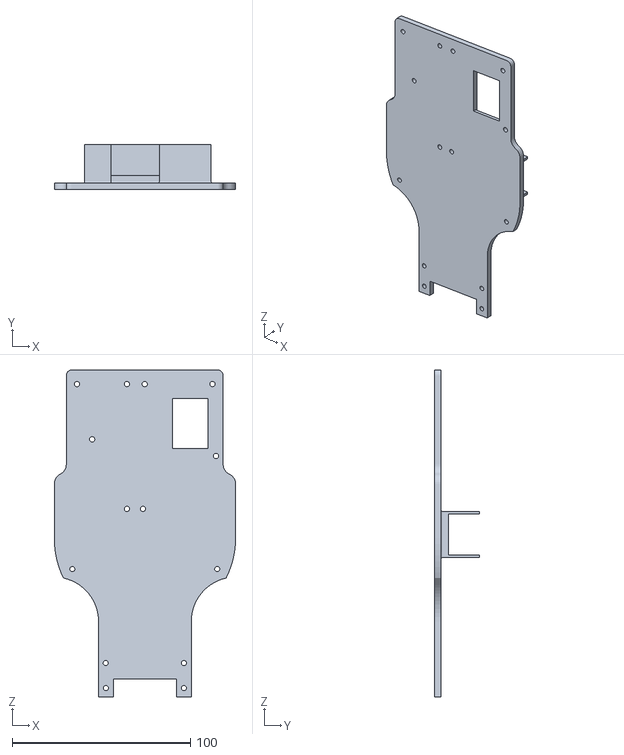
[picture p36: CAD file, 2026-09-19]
models/Base Plate.stl
101.7 x 25.1 x 183.5

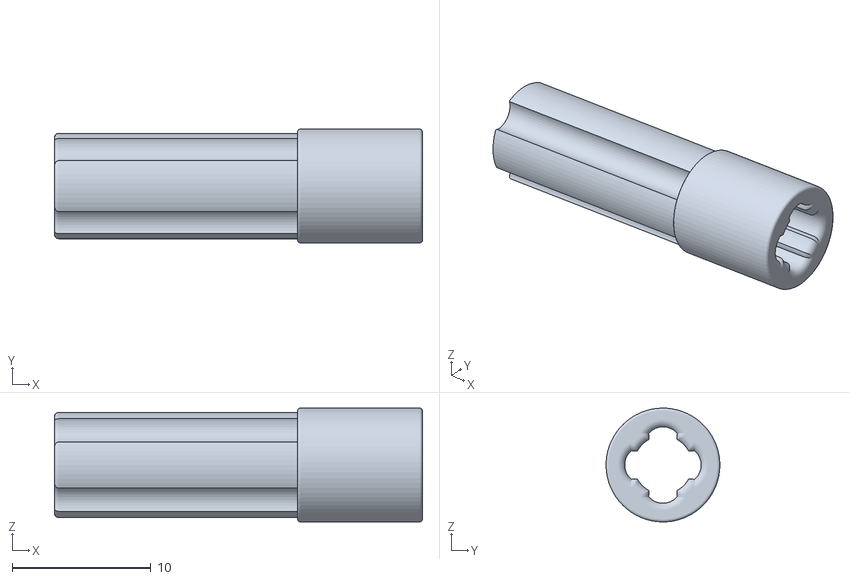
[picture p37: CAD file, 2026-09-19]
models/LEGO Shaft.stl
26.5 x 8.20 x 8.20

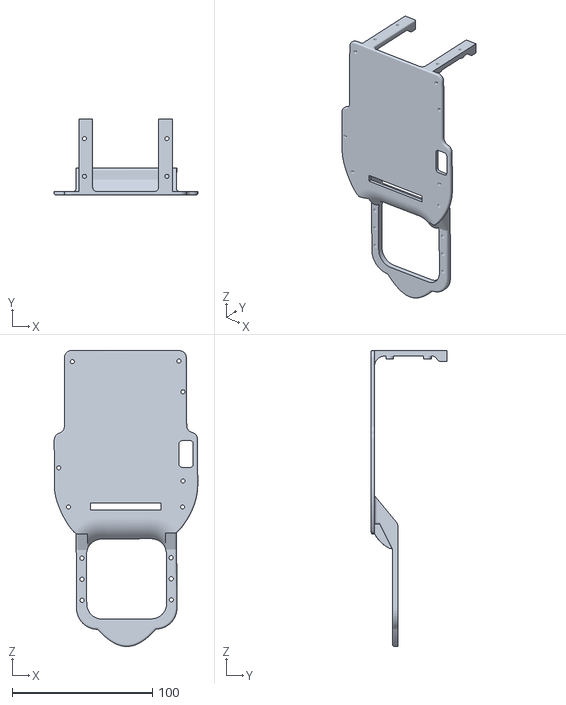
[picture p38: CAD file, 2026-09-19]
models/Middle Plate.stl
102.4 x 54.1 x 211.0

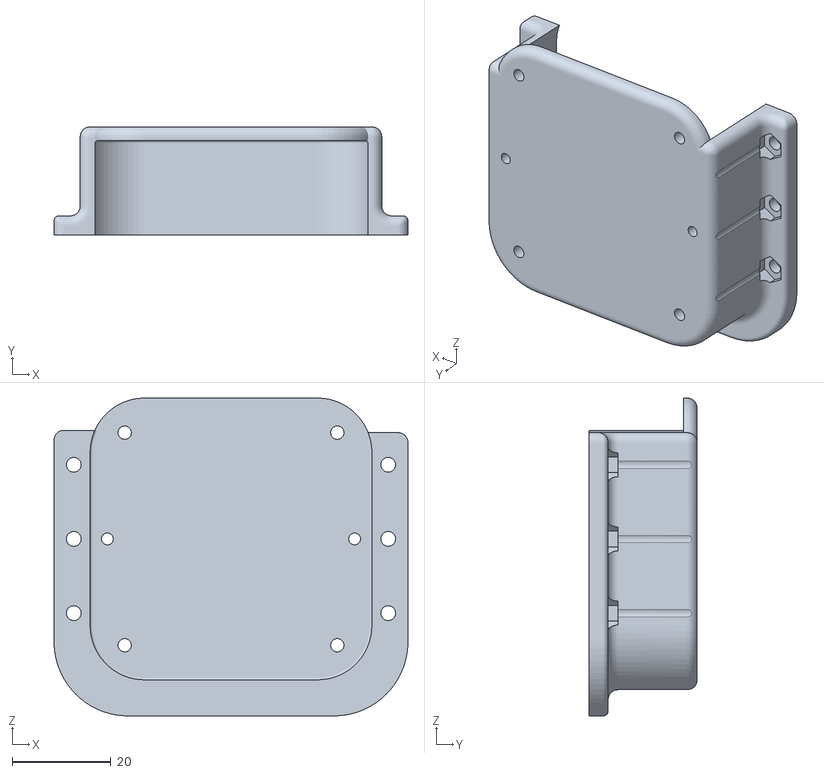
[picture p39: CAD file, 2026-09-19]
models/LiDAR mount.stl
71.6 x 21.9 x 64.3

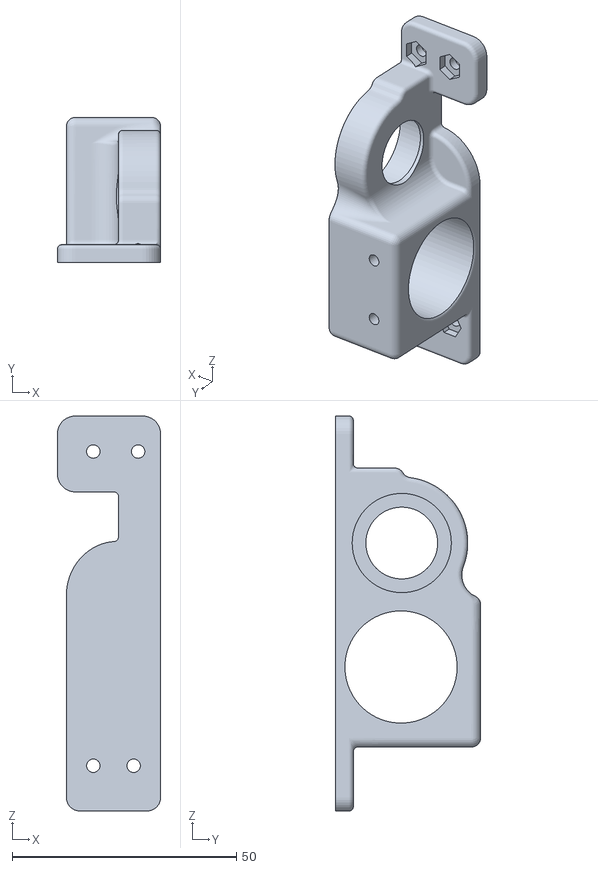
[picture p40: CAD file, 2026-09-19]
models/Motor Mount .stl
23.0 x 32.3 x 88.0

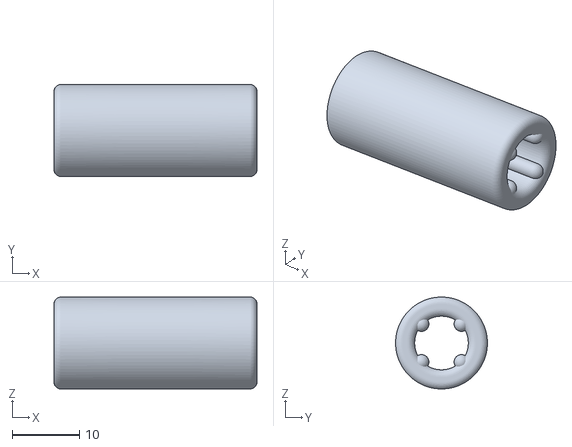
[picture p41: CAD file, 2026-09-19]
models/Connector B22.stl
30.3 x 13.7 x 13.7

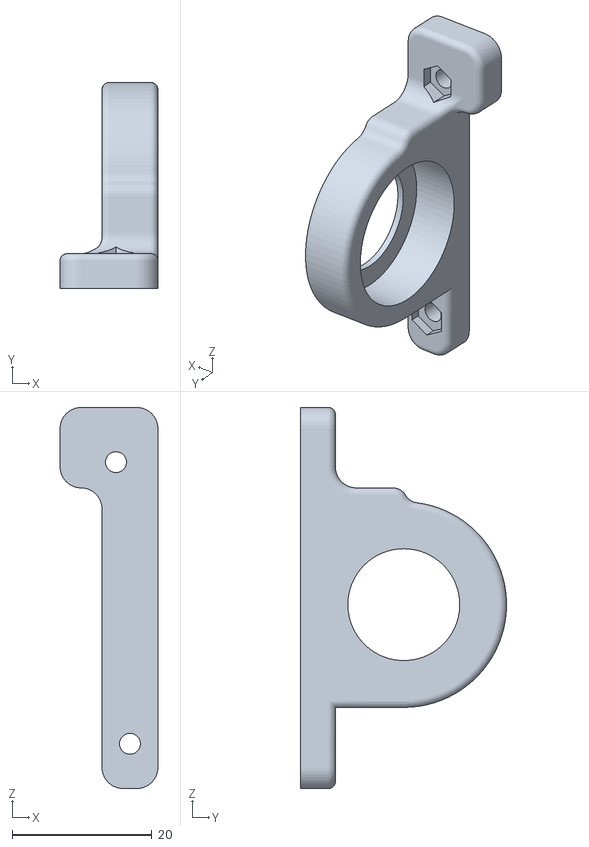
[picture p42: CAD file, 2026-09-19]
models/Right Bearing Mount.stl
14.0 x 29.5 x 54.5

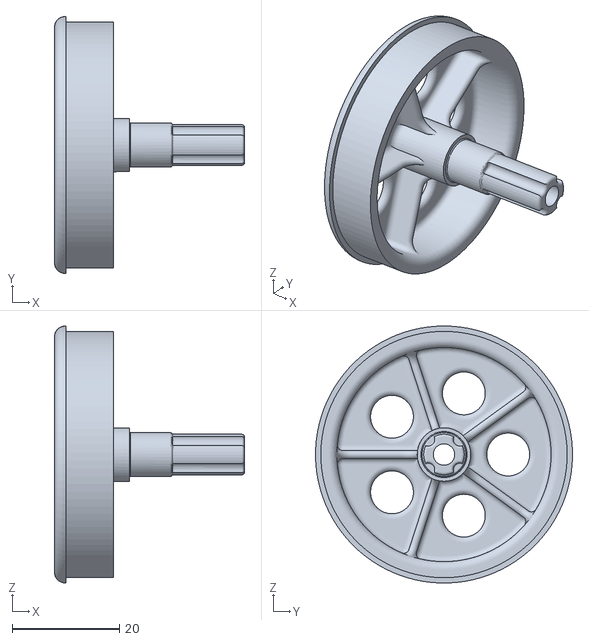
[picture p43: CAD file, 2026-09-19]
models/Left Rare Wheel New.stl
35.5 x 48.0 x 48.0

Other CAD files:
models/Left Front Wheel.stl
models/Center BR.stl
models/Right Front Wheel.stl
models/Front Bumper v45.stl
models/Front Bumper.stl
models/LEGO Gear BOX.stl
models/Left BR.stl
models/Left Stearing Hand.stl
models/Motor Mount.stl
models/Right BR.stl
models/Right Rare Wheel.stl
models/Right Stearing Hand.stl

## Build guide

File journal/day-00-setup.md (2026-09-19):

# Day 00 — Project setup (2026-07-12)

## What happened
Initialised the WRO Future Engineers 2026 project structure in the local clone of
`ShammanRahin/WRO_TeamBluePrint`.

- Verified toolchain: git 2.47.1, PowerShell, Desktop Commander all working.
- Found no existing local clone (only an unzipped template + a loose CAD folder).
  Cloned the repo fresh to the local workspace.
- Kept the WRO-standard template dirs (`t-photos, v-photos, video, schemes, src,
  models, other`) that judges expect.
- Added custom working dirs alongside them: `journal/`, `3D-models/`,
  `electrical/`, `media/` (`src/` already present).
- Created source-of-truth docs: `SPECSHEET.md`, `DECISIONS.md`, `BOM.md`.
- Kept the template `README.md` (to be rewritten to ≥5000 chars later per rubric).

## Decisions carried in (see DECISIONS.md)
Nav = gyro heading-hold with IMU-terminated 90° turns; STM32-only open round,
Pi + fisheye for obstacle round over checksummed UART; bell-crank steering with
AS5600 on the shaft, µs commanding; Sharp IR + sonar, ToF rejected, LIDAR deferred;
bearings everywhere, geometry-located parts, no jumpers/breadboard, star ground.

## Open questions blocking Day 1 (see full list below)
1. ⚠️ Hand-rotate encoder count: 180 counts per WHEEL rev or per MOTOR rev? — blocks odometry math.
2. ⚠️ BD national competition date — sets all three commit deadlines.
3. Servo / camera / sensors: owned vs to-buy + Daraz/RoboticsBD lead times — blocks BOM + ordering.
4. ⚠️ Corridor width in national rules (1 m or 0.6 m) — blocks geometry (R, lock, width).
5. Actual wheel diameter — blocks odometry + R.

## Update (2026-07-12) — open questions answered
1. **Encoder:** working assumption 180 counts per WHEEL rev; Shanto to recount and correct. (placeholder)
2. **Competition:** October (national). Exact date still needed to pin commit deadlines.
3. **Parts:** MG996R servo (owned — confirmed from Fusion model 2026-07-12; earlier note said MG90S, corrected), VL53L1X ToF ×5 (owned), Raspberry Pi 4B 1 GB (owned), fisheye lens (owned). Sharp IR bought only if required. → BOM updated.
4. **Corridor width:** 1 m (national). → geometry unblocked.
5. **Wheel diameter:** free — 3D printer on hand, print any wheel. Treated as a design variable (start 45 mm).

**⚠️ Conflict logged:** VL53L1X ToF reverses Decision #7's "ToF rejected". Recorded as a team override with risk + mitigation in DECISIONS.md #7 and SPECSHEET §8. Must validate on the real mat; Sharp IR/sonar kept as documented fallback.

## Next
Lock Day-1 geometry (wheelbase, steering lock, length, width, starting wheel dia)
into SPECSHEET.md now that corridor = 1 m. Confirm encoder count. Get exact
competition date to set the three commit deadlines.

## Reminder to self
Design phase produces a justified, print-ready v1 — NOT a finished car.
Competition-level is earned by testing on a real mat in Sept–Oct.
Nothing gets pushed unreviewed.

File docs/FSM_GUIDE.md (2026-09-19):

# How to Write the Control Logic

`control/fsm.py` is a working skeleton with the driving decisions left as
`TODO` blocks. This document explains what goes in each one, what tools you
have, and the traps specific to this car and this rulebook.

Read the contract first, then the per-state sections.

---

## The contract every handler obeys

```python
def on_something(ctx: Ctx, st: RunState) -> ActionIntent:
    ...
    return ActionIntent.hold_heading(st.lane_heading, 400, reason="why")
```

Four rules, and breaking any of them breaks the whole loop:

1. **Return an `ActionIntent` every time.** No exceptions, no `None`. The
   control loop is not allowed to skip a tick.
2. **Never block.** No `sleep()`, no `while` waiting for something, no serial
   reads. You are called ~30×/second and must return in well under a
   millisecond. To "wait", stay in the state and check a condition each tick.
3. **Transition with `st.go(State.X)`.** It takes effect *after* your return,
   so you still return the intent for this tick. Handlers never call each other.
4. **Persist in `st`, not in globals.** `ctx` is this tick; `st` is the run.
   Anything remembered across ticks goes in `RunState` so a reset is one line.

### What you can see (`ctx`)

| | |
|---|---|
| `ctx.obstacles` | fused camera+lidar pillars: `.color`, `.bearing_deg` (+ = left), `.distance_mm` (inf if no lidar return), `.confidence` |
| `ctx.nearest("RED","GREEN", max_dist_mm=900)` | closest match, or `None`. **Skips obstacles with no range** — you can't do geometry without a distance |
| `ctx.heading` | degrees, + = left of the boot heading, wrapped ±180 |
| `ctx.odo_mm` | cumulative odometry. Take *differences*; the absolute value is arbitrary |
| `ctx.front_mm` / `.left_mm` / `.right_mm` | ToF, `inf` when invalid |
| `ctx.floor` | `FLOOR_NONE` / `FLOOR_ORANGE` / `FLOOR_BLUE` from the down-facing TCS34725 |
| `ctx.now`, `ctx.dt` | use these, not `time.time()`, so a tick is internally consistent |

### What you remember (`st`)

`st.dist_in_state(ctx)` and `st.time_in_state(ctx)` are how you terminate
legs. Every field in `RunState` has a comment; add more freely.

### What you can ask for

```python
ActionIntent.hold_heading(heading_deg, speed_mmps, reason="")  # straights
ActionIntent.steer(angle_deg, speed_mmps, reason="")           # arcs, + = left
ActionIntent.stop(reason="")                                    # motor off
```

`speed_mmps` may be negative to reverse. The mapper clamps everything to the
car's real limits, so asking for 90° or 5000 mm/s is safe — you get 35° and
700 mm/s. Always fill in `reason`: it prints on the status line and it is what
you'll read when a run goes wrong.

### Geometry helpers (`control.mapper`)

These exist so you write physics, not magic numbers:

```python
steer_for_radius(194.4)                     # → 35.0°  (that's full lock)
radius_for_steer(20)                        # → 374 mm
steer_for_lateral_shift(250, 800)           # +250mm sideways over 800mm → +6.1°
```

Car facts, CAD-verified: wheelbase **136.14 mm**, lock **±35°**, minimum turn
radius **194.4 mm**, top speed **700 mm/s**, body **165 × 114 mm**.

---

## Global invariants

These hold everywhere and the skeleton already enforces the first two:

- **Stale telemetry or a tripped watchdog → STOP**, checked above every
  handler in `FSM.step()`. No TODO you leave can drive the car blind.
- **Front ToF below `WALL_PANIC_MM` (200 mm) → `RECOVER`**, wired into `DRIVE`
  and `AVOID`. Add it to any new state that moves forward.
- **"The heading is the truth."** Terminate manoeuvres on *measured heading*,
  never on steering angle or elapsed time. Tyre slip corrupts the latter two;
  the IMU is immune.
- **Always add an odometry backstop.** Any state that waits for a sensor event
  must also give up after a distance (`st.dist_in_state(ctx)`). A dead sensor
  must not hang the run.

---

## `on_drive` — the straight

This is the dispatcher. Hold the lane, watch for three events.

### Why corner beats pillar

Evaluate the corner check **before** the pillar check, and don't start an
avoidance once a corner has armed. The asymmetry is deliberate:

> Missing a pillar forfeits points. Missing a corner ends the run.

An avoidance already in progress finishes first — it's `AVOID`'s job to
complete, not to be interrupted mid-swerve.

### Corner detection and direction decode

Two things make this harder than "saw a line, turn":

**Every corner has both an orange and a blue line** (rule 13.9). A naive
trigger fires ~24 times over 3 laps, not 12. Use `st.line_lockout_until_mm`:
after a turn completes, ignore all floor colour until `ctx.odo_mm` passes
that mark (`POST_CORNER_LOCKOUT_MM`, 500 mm is the proven value).

**The driving direction is drawn randomly per round** (rule 9.3), so you can't
hardcode turn direction. The first line pair of the run decodes it: orange
first → clockwise → all 12 corners are right turns; blue first → counter-
clockwise → all left. Store it in `st.clockwise` and never re-decide. Until
it's set, you don't know which way to turn.

The line *arms* the corner; the turn *fires* when the front ToF confirms the
wall is close (`FRONT_TURN_MM`, 700 mm) — or on a distance backstop if no ToF
is working. Colour alone is the degraded fallback, not the primary.

On firing: step `st.lane_heading` by ±90 (sign from `st.clockwise`), then
`st.go(State.TURN)`.

### Pillar engagement

```python
pillar = ctx.nearest("RED", "GREEN", max_dist_mm=PILLAR_ENGAGE_MM)
```

Rule 9.19 is absolute: **red is passed on the right, green on the left.**
Set `st.avoid_color`, `st.avoid_side` (+1 left, −1 right), and
`st.avoid_entry_odo_mm` *before* transitioning so `AVOID` knows its job.

---

## `on_avoid` — threading a pillar

The corridor is 1000 mm; the pillar is 50 mm square, sitting somewhere in it.
You need to be on the legal side by the time you arrive, then return to the
lane.

Two approaches, both valid:

**Phased** (what `ObstacleRound.cpp` did): swerve out → straighten → hold →
return → realign, with a sub-phase counter in `st`. Each phase terminates on
distance or heading. Predictable, easy to debug, more code.

**Continuous**: each tick, compute the lateral shift you still need and convert
it to an angle with `steer_for_lateral_shift(shift, distance_to_pillar)`.
Fewer states, naturally handles the pillar moving in the frame, but you must
handle the pillar leaving the frame (`distance_mm` goes `inf`, or `nearest`
returns `None`) without lurching.

Whichever you pick: remember the displacement you committed to
(`st.avoid_shift_mm`) so the return leg is symmetric. Keep a hard floor of
~100 mm from any wall. Release when the pillar is passed
(`PILLAR_CLEAR_MM`) or gone, then rejoin `st.lane_heading` and
`st.go(State.DRIVE)`.

---

## `on_turn` — the corner

```python
error = wrap180(st.lane_heading - ctx.heading)   # lane_heading already stepped ±90
```

Ease both steering and speed down as `|error|` shrinks, so you don't overshoot
the exit. The proven shape from the C firmware:

```
steer = clamp(K_turn × |error|, TURN_MIN_STEER, TURN_MAX_STEER)
speed = clamp(K_v    × |error|, TURN_MIN_SPEED, TURN_MAX_SPEED)
```

Terminate at `|error| < TURN_DONE_TOL_DEG` — no settle delay, residual error
gets absorbed on the next straight. Add an odometry cap (~1200 mm) so a dead
IMU can't hang the state.

On completion: `st.corner_count += 1`, then `st.go(State.LANE_CORRECT)`.

---

## `on_lane_correct` — the radial-line ruler

Optional; the skeleton passes straight through so you can bring everything
else up first.

The insight (full version in `control_architecture.md` §6): the orange and
blue corner lines **fan out radially**, so the encoder distance between
crossing them measures how far you are from the inner wall. The encoder is the
one sensor immune to optical noise.

Measure the gap at corner 1 and store it as `gapRefCm` — self-referenced, so
the car holds whatever line it started on rather than assuming an ideal
position. On later corners, `error = measured − reference`, convert to a
steering offset (4°/cm worked, capped at 30°), hold it for 25 cm at reduced
speed, then ease back. Deadband 2 cm to stop hunting; skip the correction
entirely if the partner line was never seen.

---

## `on_park` — the hard one

**22 of 122 points, and the geometry does not work the obvious way.**

`SPECSHEET.md` §3 is blunt: a two-arc park is **not feasible** at 35° lock.
R/L = 0.95, best clearance −25.6 mm — the front outer corner sweeps into the
entry limiter at ~37° heading. Raising the lock doesn't save it (40° still
collides, 45° merely touches). And the problem is **scale-invariant**: the bay
is always 1.5 × car length, so shortening the car shrinks the bay too.

Decision #21 was amended accordingly: **multi-point shuffle**. Enter at
whatever angle fits, then alternate short forward/reverse legs, straightening
against IMU yaw each time.

Practical shape: phase it with `st.park_phase`. Each phase is one short leg —
fixed steer angle, `PARK_SPEED_MMPS` (slow), terminated on
`st.dist_in_state(ctx)` or on heading error. Find the bay with
`ctx.nearest("MAGENTA")`.

The exit test is **heading**, not position: "parallel" means both same-side
wheels within 20 mm of the wall, which is an angular condition.

Touching a limiter is rule 9.24.7 — **instant zero for parking**. Slow and
repeatable beats fast and clever here. This is also the state that most
depends on `TICKS_PER_CM` being correct; see the protocol doc's warning.

---

## `on_recover` — the failsafe

Reverse on mirrored steering until `ctx.front_mm` is comfortable (~350 mm) or
a distance cap is hit, then `st.go(st.recover_return_state)` — the state that
called you, already stored.

Bound it: increment `st.recover_attempts`, and after ~3 tries give up into
`FINISHED` rather than bumping a wall forever. Ignore floor lines while
reversing, or you'll re-cross a corner line backwards and corrupt the count.

---

## Testing without the car

```bash
python3 main_obstacle.py --dry
```

runs the FSM with no serial port at all. Telemetry stays empty, so the
staleness override keeps it in STOP — useful for confirming perception and the
tick rate, not for logic.

To exercise logic properly, drive the FSM with synthetic telemetry:

```python
from control import FSM, Ctx, Telemetry, State
import time
fsm = FSM(on_transition=lambda o,n: print(o.name, "->", n.name))
t = Telemetry(stamp=time.time(), button_pressed=True,
              heading_deg=0.0, tof_front_mm=900.0, distance_mm=0.0)
intent = fsm.step(Ctx(telem=t, obstacles=[], now=time.time()))
print(fsm.st.state.name, intent.reason)
```

Build the scenario you care about — a pillar at a bearing, a floor colour, a
heading error — and assert the state and intent. This is far faster than
finding logic bugs on the mat, and it costs nothing to keep as a test file.

---

## Order I'd build them in

1. `on_drive` cruise + `on_turn` — get it round one lap with no pillars.
2. Corner counting and the direction decode — get 12 corners reliable.
3. `on_avoid` — add pillars.
4. `on_lane_correct` — tighten up the lane over 3 laps.
5. `on_park` — last, because it's the most geometry and the most tuning.

Each step is independently testable on the mat, and each one is worth points
on its own.

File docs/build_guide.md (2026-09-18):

# Build Guide & Mechanical Fabrication

> Complete step-by-step instructions for manufacturing, assembling, and wiring the **Team Blueprint** autonomous vehicle from scratch.
> For a high-level system overview, return to the **[Master README](../README.md)**.

---

## 1. System Bill of Materials Overview

| Subsystem | Component | Specification / Part Number | Notes |
|:---|:---|:---|:---|
| **Real-Time Controller** | WeAct BlackPill | STM32F411CEU6, ARM Cortex-M4 @ 100 MHz | Hardware FPU, 512KB Flash |
| **High-Level Compute** | Raspberry Pi 5 | 8 GB RAM, Quad-Core Cortex-A76 @ 2.4 GHz | Active cooler fitted (Obstacle round) |
| **Drive Motor** | 25GA-370 DC Gearmotor | 12V, 1331 RPM motor shaft, Hall quadrature encoder | 5:1 spur reduction to rear axle |
| **Motor Driver** | BTS7960 H-Bridge | Dual-channel high-power MOSFET driver, 43A rating | Direct battery rail |
| **Steering Servo** | JX PS-1171MG | 17g digital metal-gear servo | Dedicated 6.0V 3A buck rail |
| **Inertial Measurement** | BNO085 breakout | 9-axis IMU with on-chip sensor fusion (SPI mode) | Game rotation vector (no magnetometer) at ~100 Hz |
| **I2C Multiplexer** | TCA9548A / PCA9548A | 8-channel bidirectional I2C switch (Address `0x70`) | Isolates sensors at address `0x29` |
| **Distance Sensors** | VL53L0X (Open fw: 1× front) / VL53L1X (Obstacle fw: left, right, front) | ToF, one per mux channel | Printed slot collimators + 2° wedge |
| **Floor Color Sensor** | Adafruit TCS34725 | RGB sensor with IR filter and white illumination LED | Downward facing with light hood |
| **Perception Sensor** | Slamtec RPLIDAR C1 | 360° DTOF 2D LiDAR scanner, 12m range, 5 kHz | USB serial interface to Pi 5 |
| **Optical Camera** | 160° FoV Fisheye | Wide-angle Pi camera module (CSI, Picamera2) | Pillar colour + bearing |
| **Battery** | 3S LiPo Battery | 11.1V nominal, 75C discharge rating | XT30 connector specified (see Decision #26) |

---

## 2. 3D Printing Specifications

All structural components are designed in **Autodesk Fusion 360** and sliced for an **Ender 3 V3 SE** in **PLA**.

| Component | Infill Density | Wall Count | Notes & Constraints |
|:---|:---:|:---:|:---|
| **Chassis Base Plate** | 5% | 3 | $130 \times 80\text{ mm}$ plate (see SPECSHEET §3) |
| **Body Shell & Brackets** | 5% | 2 | Lightweight shell to maintain low center of gravity |
| **Drive Gears** | **90%** | 4 | **Must be printed dense** to resist tooth shearing under motor stalls |
| **Front Wheels (46 mm)** | 5% | 3 | Fitted with silicone/rubber O-rings for traction |
| **Rear Wheels (50 mm)** | 5% | 3 | Keyed to solid steel drive shaft |
| **Ackermann Knuckles & Tie-Bar** | 15% | 4 | $\pm 35^\circ$ travel without mechanical interference |
| **ToF Optical Collimator Snouts** | 10% | 3 | $2.5 \times 10 \times 20\text{ mm}$ aperture + $2.0^\circ$ wedge |
| **TCS34725 Light Hood** | 15% | 3 | Prevents ambient arena lighting from washing out floor lines |
| **Camera & LiDAR Mast** | 10% | 3 | Elevated $\approx 90\text{ mm}$ for unobstructed $360^\circ$ LiDAR beam |

> CAD source models and printable `.stl` files belong in the [`models/`](../models/README.md) directory. **They have not been uploaded yet** — this is a WRO documentation requirement.

---

## 3. Printed Circuit Boards (PCBs)

Because the local fab (Dhaka) makes only single-sided boards without plated through-holes, the electronics are split across two single-sided PCBs (see [`electrical/DESIGN_RULES.md`](../electrical/DESIGN_RULES.md)):

* **Upper Carrier Board ($90 \times 70\text{ mm}$)**:
  * Mounts the STM32 BlackPill, BTS7960 logic interface, BNO085 IMU, pushbuttons, and primary power distribution.
  * Designed with conservative $0.6\text{ mm}$ trace widths and $0.6\text{ mm}$ clearances.
  * Raspberry Pi 5 mounting footprint positioned directly above for compact vertical stacking.
* **Lower Sensor Breakout Board**:
  * Carries the TCA9548A multiplexer and local latching headers for ToF and color sensors.
  * Connected to the Upper Carrier Board via a $\sim 40\text{ mm}$ 6-pin JST-XH cable (grounds on both outer pins, twisted SCL/SDA).

### Wiring & Avionics Standards
* **Zero DuPont Jumpers**: Jumper wires are strictly prohibited on competition hardware.
* **Latching JST-XH Connectors**: All sensor, servo, and serial connections utilize genuine JST-XH crimped pins with heat-shrink strain relief.
* **High-Current Power Rails**: Motor B+ and B- run directly from the battery harness to the BTS7960 via screw terminals with wire ferrules—high currents never cross milled PCB traces.
* **Isolated Grounds & Power Domains**: See [`electrical/ELECTRICAL.md`](../electrical/ELECTRICAL.md) for star ground topology and current budgets.

---

## 4. Step-by-Step Assembly Sequence

```mermaid
flowchart TD
    A["1. Front Steering Assembly<br/>(Ackermann linkage, check angles)"] --> B["2. Powertrain & Drivetrain<br/>(Motor, 5:1 spur gears, solid axle)"]
    B --> C["3. Lower Sensor Board & Mounts<br/>(Collimated ToFs, TCS light hood)"]
    C --> D["4. Upper Electronics Carrier<br/>(BlackPill, IMU, power regulators)"]
    D --> E["5. Perception Tier<br/>(Pi 5 stack, RPLIDAR C1, fisheye camera)"]
    E --> F["6. Bench Electrical Check<br/>(Rail-by-rail voltage verification)"]
```

### Step 1: Front Steering Linkage
1. Assemble the steering knuckles onto the chassis base plate using stainless steel pivot shoulder screws and miniature ball bearings.
2. Connect the Ackermann tie-bar to both knuckle horns.
3. **Verification**: Confirm that the knuckle pivot centres stay fixed during steering. Verify that the inner wheel turns sharper than the outer wheel at full lock ($\cot\delta_o - \cot\delta_i \approx K_w/L$).
4. Center the JX PS-1171MG digital servo and connect the linkage pushrod.

### Step 2: Drivetrain & Rear Axle
1. Press-fit ball bearings into the rear axle chassis brackets.
2. Slide the precision steel drive shaft through the bearings, installing the 5:1 spur gear.
3. Lock both rear wheels to the axle shaft using transverse grub screws.
4. Mount the 25GA gearmotor, verifying backlash-free spur mesh with the axle gear.
5. Secure the motor encoder cable, routing it away from high-current motor leads.

### Step 3: Sensors & Optical Baffles
1. Install the 3D-printed $+2.0^\circ$ mounting wedges and slot collimators on the ToF sensors (front VL53L0X for the current Open program; left/right/front VL53L1X for the Obstacle program).
2. Mount the downward-facing TCS34725 color sensor with its ambient light hood positioned $8\text{ mm}$ above the ground.
3. Secure the lower sensor PCB and connect all sensor harnesses.

### Step 4: Carrier Board & Power Distribution
1. Mount the Upper Carrier Board using nylon M3 standoffs.
2. Connect the 6.0V buck regulator to the servo rail and the 5.0V buck regulator to the MCU/sensor rail.
3. Wire the master toggle switch (WRO Rule 9.10) to the battery input harness.
4. Wire the momentary start button (WRO Rule 9.11): `PA5` on the earlier pin map used by `ObstacleRound.cpp`; `PB15` is reserved for it on the current carrier used by `OpenRound.cpp` (not yet read by that firmware).

### Step 5: High-Level Perception Stack
1. Mount the Raspberry Pi 5 onto the upper carrier board standoffs.
2. Install the rigid sensor mast ($90\text{ mm}$ height) and bolt the RPLIDAR C1 scanner to the top platform.
3. Mount the 160° fisheye camera, ensuring its optical axis is horizontal and aligned with the vehicle centerline.
4. Connect the dedicated 5.0V/5.1V 5A buck regulator harness to the Pi 5 USB-C / GPIO power inputs.

### Step 6: Electrical Bring-Up Order
*Follow the mandatory bring-up sequence in [`electrical/ELECTRICAL.md`](../electrical/ELECTRICAL.md) Section 10 before plugging in sensitive ICs:*
1. Power on with boards unpopulated; measure 6.0V on servo rail, 5.0V on logic rail, and battery voltage on BTS7960 rail.
2. Plug in the STM32 Black Pill; confirm the 3.3 V regulator output.
3. Connect sensors one by one, checking I2C bus communication with an I2C scanner sketch.
4. Connect the Raspberry Pi 5 and confirm stable 5.1V under load with zero undervoltage warnings.

---

## 5. Firmware Flashing & Software Setup

### STM32 Real-Time Firmware
There is no PlatformIO project in the repository. Build with the **Arduino IDE + STM32duino core**:

1. Install the *STM32 MCU based boards* core and the libraries SparkFun BNO08x Arduino Library, Adafruit TCS34725, and Pololu VL53L0X (open round) or VL53L1X (obstacle round).
2. Copy `OpenRound.cpp` / `ObstacleRound.cpp` into a sketch folder of the same name as `OpenRound.ino` / `ObstacleRound.ino`.
3. Board *Generic STM32F4 series* → *BlackPill F411CE*, USB support *CDC (generic Serial)*, upload method *STM32CubeProgrammer (DFU)*.
4. Enter DFU (hold BOOT0, tap NRST, release BOOT0) and upload.

### Raspberry Pi Perception Setup
```bash
cd src/pi
python3 -m venv --system-site-packages ~/robo-env   # picamera2 comes from apt
source ~/robo-env/bin/activate
pip install -r requirements.txt

# Start the perception and fusion pipeline (prints fused obstacles)
python3 main.py
```

After flashing and initial power-up, proceed immediately to the **[Calibration Guide](calibration.md)**.

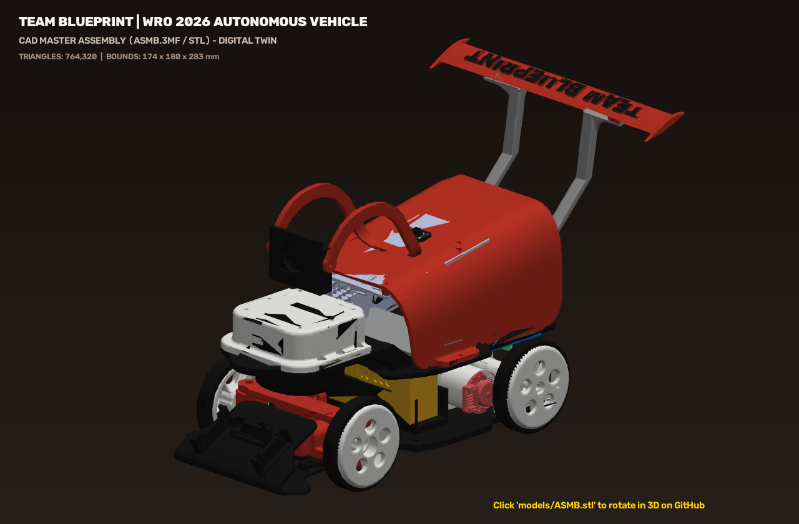
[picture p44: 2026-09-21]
media/bot/cad_assembly_render.png

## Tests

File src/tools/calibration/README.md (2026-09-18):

# Calibration sketches

Eight standalone sketches, one per calibration step, plus a menu-driven suite
that runs all eight from one flash.

The full procedure — what rig you need, what to expect, how to read the output,
and what to do when it looks wrong — is in
[`docs/calibration.md`](../../../docs/calibration.md). Read that first. These
files are the tools; that page is the method.

> ⚠️ `hardware_config.h` still holds the **earlier pin map** (motor PB9/PB8, encoder
> TIM3 on PA6/PA7, IMU on PB3–PB5, button PA5). The current carrier used by
> `OpenRound.cpp` is re-pinned — update this header before running these sketches on it.

| File | Step |
|---|---|
| [`hardware_config.h`](hardware_config.h) | shared pins, constants and helpers — **edit pins here only** |
| [`01_encoder_ticks_per_rev.cpp`](01_encoder_ticks_per_rev.cpp) | encoder ticks per wheel revolution |
| [`02_ticks_per_cm.cpp`](02_ticks_per_cm.cpp) | ticks per centimetre, by regression |
| [`03_steering_jerk.cpp`](03_steering_jerk.cpp) | steering jerk vs servo slew limit |
| [`04_true_straight_servo.cpp`](04_true_straight_servo.cpp) | true straight servo angle |
| [`05_tof_signal_threshold.cpp`](05_tof_signal_threshold.cpp) | ToF floor signal threshold |
| [`06_turn_90.cpp`](06_turn_90.cpp) | ninety degree turn law |
| [`07_heading_gain.cpp`](07_heading_gain.cpp) | heading hold gain |
| [`08_floor_colour_thresholds.cpp`](08_floor_colour_thresholds.cpp) | floor colour cut points |
| [`CalibrationSuite.cpp`](CalibrationSuite.cpp) | all eight behind a serial menu |

Run them in order the first time: 2 needs 1, 4 needs 2, 6 needs 4, 7 needs 6.
Steps 3, 5 and 8 are independent.

Each file is a self-contained Arduino sketch with its own `setup()` and
`loop()`. Flash one at a time — do not try to compile the folder as a unit.

Steps 2, 3, 4, 6 and 7 drive the motor. Put the car on the floor with a clear
run ahead of it, never on a bench edge. Every one of them waits for the start
button before it moves.

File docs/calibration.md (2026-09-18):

# Sensor & Actuator Calibration Guide

> An empirical, 8-step calibration protocol ensuring every mathematical constant in the vehicle firmware reflects physical reality.
> For a high-level system overview, return to the **[Master README](../README.md)**.

---

## 1. Calibration Architecture & Dependencies

Every constant in this vehicle was experimentally measured rather than estimated. The calibration steps must be performed in strict dependency order on the first setup, as downstream calculations depend directly on prior measurements.

```mermaid
flowchart LR
    S1["1 · encoder ticks<br/>per revolution"] --> S2["2 · ticks per<br/>centimetre"]
    S2 --> S4["4 · true straight<br/>servo angle"]
    S4 --> S6["6 · ninety degree<br/>turns"]
    S6 --> S7["7 · heading<br/>correction gain"]
    S3["3 · steering jerk"]:::indep
    S5["5 · ToF floor signal<br/>threshold"]:::indep
    S8["8 · floor colour<br/>thresholds"]:::indep
    classDef indep stroke-dasharray: 5 4
```

* **Solid arrows**: Strict sequential dependencies (e.g., Step 2 requires the output of Step 1).
* **Dashed boxes**: Independent steps that can be re-run at any time.

### Prerequisite Checklist
* **Competition Weight**: All calibration must be conducted with the vehicle in full competition trim: 3S battery installed, body shell mounted, and camera mast secured. Tyre squash under real vehicle load changes the effective rolling radius.
* **Pin map**: The calibration sketches use the *earlier* pin map in `hardware_config.h` (motor PB9/PB8, encoder TIM3 on PA6/PA7, IMU SPI on PB3–PB5). The current carrier used by `OpenRound.cpp` is re-pinned (motor PA2/PA3, encoder TIM5 on PA0/PA1, IMU SPI on PA5–PA7) — update `hardware_config.h` before running these sketches on it.
* **Firmware Sketches**:
  * Standalone diagnostic sketches: [`src/tools/calibration/01_encoder_ticks_per_rev.cpp`](../src/tools/calibration/01_encoder_ticks_per_rev.cpp) through [`08_floor_colour_thresholds.cpp`](../src/tools/calibration/08_floor_colour_thresholds.cpp).
  * Pit menu runner: [`src/tools/calibration/CalibrationSuite.cpp`](../src/tools/calibration/CalibrationSuite.cpp) (flash once, select test via Serial monitor).
  * Hardware pin configurations: [`src/tools/calibration/hardware_config.h`](../src/tools/calibration/hardware_config.h).

---

## 2. Step 1: Encoder Ticks per Wheel Revolution

<p align="center">
  Histogram of 100 revolutions
</p>

* **Objective**: Determine raw quadrature encoder counts produced by exactly one full $360^\circ$ rotation of the drive axle.
* **Why Not Trust Datasheets**: Backlash in the 5:1 spur gears, coupler play, and microcontroller 4x quadrature edge decoding shift the real count away from nominal motor specs.
* **Apparatus**: Flat floor, fine index mark on the rear tyre sidewall aligned with an index mark on the chassis.
* **Procedure**:
  1. Align marks, zero the counter via button press.
  2. Slowly rotate the rear wheel forward by hand exactly one revolution until index marks meet.
  3. Record sample. Collect 100 consecutive rotations.
* **Interpretation**:
  * The running standard deviation must converge to < 1% of the mean.
  * A growing standard deviation indicates grub screw slippage or electrical noise on the encoder lines.

---

## 3. Step 2: Ticks per Centimetre (`TICKS_PER_CM`)

<p align="center">
  Least-squares fit of encoder ticks against measured distance
</p>

* **Objective**: Measure the real linear travel per encoder tick under competition load.
* **Current Values**: **`14.853 ticks/cm`** in `OpenRound.cpp` (0.673 mm/count; 248.8 ticks/rev over a 5.2 cm wheel) and **`31.933 ticks/cm`** in `ObstacleRound.cpp` / `hardware_config.h` (0.313 mm/count, earlier build).
* **Why Use Linear Regression**: Dividing distance by tick count on a single run bakes in acceleration ramp and stopping coast errors. By measuring across six distances ($25, 50, 75, 100, 150, 200\text{ cm}$), the startup/stopping errors isolate into the regression intercept, leaving the slope clean:
  $$\text{ticks} = m \cdot \text{distance} + c \implies \text{TICKS PER CM} = m$$
* **Apparatus**: Minimum 2 meters of authentic competition mat with high-precision tape measure.
* **Validation Criteria**: Coefficient of determination $R^2 > 0.999$. Lower values indicate tire slip or imprecise sighting.

---

## 4. Step 3: Steering Jerk & Slew Limit (`SERVO_SLEW`)

<p align="center">
  Yaw jerk trace with and without slew limiting
</p>

* **Objective**: Eliminate instantaneous steering snap to protect gears and prevent traction loss.
* **Current Value**: **`2.5 deg/cycle`**.
* **Physics of Jerk**:
  $$\text{jerk} = \frac{d^3\theta}{dt^3} = \frac{d}{dt}(\text{yaw acceleration})$$
  High yaw jerk breaks rear tire static friction on slick vinyl mats, inducing wheel scrub and corrupting encoder odometry.
* **Procedure**: Run the vehicle at competition speed into a $25^\circ$ step turn with slew limits ranging from $0$ (unlimited) to $5.0^\circ/\text{cycle}$.
* **Selection**: Select the "knee" on the jerk vs. slew curve where jerk drops substantially without making the corner entry sluggish ($< 300\text{ ms}$ settling time).

---

## 5. Step 4: True Straight Servo Angle (`SERVO_TRUE_STRAIGHT`)

<p align="center">
  Mean heading drift against commanded servo angle
</p>

* **Objective**: Find the exact digital servo command that drives the vehicle in a mathematically straight line.
* **Current Values**: **`71.0°`** in `OpenRound.cpp` (current car); **`69.0°`** in `ObstacleRound.cpp` / `hardware_config.h`, which the header notes was found on the earlier MG996R build and must be re-measured for the JX PS-1171MG.
* **Procedure**:
  1. Sweep servo commands in $0.5^\circ$ increments around nominal center.
  2. Drive $3\text{ meters}$ at each angle, recording accumulated heading drift via the BNO085.
  3. Plot drift vs. commanded angle; identify the minimum of the V-curve where heading drift equals $0.00^\circ/\text{m}$.

---

## 6. Step 5: ToF Floor Signal Threshold (`SIGNAL_MIN_MCPS`)

<p align="center">
  Signal rate for floor returns versus wall returns
</p>

* **Objective**: Distinguish between authentic black wall returns and spurious floor returns using photon count rate.
* **Current Values**: **`SIGNAL_MIN_MCPS = 4.0`**, **`TOF_MAX_VALID_MM = 1300`** (obstacle program, VL53L1X). The open program's VL53L0X path uses `TOF_MAX_VALID_MM = 1200` and no signal filter.
* **Principle (from the step-5 sketch)**: matte black walls return weak signal; the white mat returns strong signal. Measure both and set the threshold in the gap.
* **Procedure**: Log signal rate for open floor (no wall in range) and for a black wall at 200–1200 mm; plot both populations and place the threshold in the gap.
* ⚠️ **Known inconsistency**: the sketch describes a *ceiling* (discard strong returns), but `ObstacleRound.cpp` implements a *floor* (`signal >= SIGNAL_MIN_MCPS` is kept, weak returns are discarded). Decide from the logged data which one is right and fix the other.

---

## 7. Step 6: 90-Degree Eased Turns

<p align="center">
  Final heading error histograms for left and right turns
</p>

* **Objective**: Tune the proportional eased cornering controller.
* **Current Values** (both programs): `TURN_KP = 2.5`, `TURN_KV = 3.5`, `TURN_MIN_STEER = 8°`, `TURN_MAX_STEER = 55°`, `TURN_STOP_DEG = 0.3°`, `TURN_MIN_PWM = 100`, `TURN_MAX_PWM = 130`.
* **Control Law**:
  $$\text{error} = \theta_{\text{target}} - \theta_{\text{current}}$$
  $$\text{steer} = \text{clamp}(K_{p,\text{turn}} \cdot |\text{error}|,\  \text{TURN MIN STEER},\  \text{TURN MAX STEER})$$
  $$\text{pwm} = \text{clamp}(K_{v,\text{turn}} \cdot |\text{error}|,\  \text{TURN MIN PWM},\  \text{TURN MAX PWM})$$
* **Validation**: Run 30 consecutive alternating turns (15 left, 15 right). Final heading error standard deviation must stay under $1.5^\circ$. If left and right errors diverge systematically, re-run Step 4.

---

## 8. Step 7: Straight-Line Heading Hold Gain (`HEAD_KP`)

<p align="center">
  RMS heading error and zero crossings against gain
</p>

* **Objective**: Tune the cruise heading hold P-gain.
* **Current Values**: **`HEAD_KP = 2.0`**, **`HEAD_KI = 0.0`**, **`HEAD_KD = 0.0`**, **`YAW_FILT_ALPHA = 0.35`**.
* **Tuning Method**:
  1. Increment $K_p$ on a $4\text{-meter}$ straight until the vehicle visibly oscillates (snaking period $\approx 0.5\text{ s}$).
  2. Reduce $K_p$ to 60% of the oscillation onset gain.
  3. $K_i$ is kept at 0 (eliminates integral windup and prevents masking mechanical steering misalignment).
  4. $K_d$ is kept at 0 (it would act on the filtered yaw rate; the P term alone was sufficient).

---

## 9. Step 8: Floor Colour Ratio Thresholds

<p align="center">
  Red against blue channel percentages
</p>

* **Objective**: Classify track lines into ORANGE, BLUE, or WHITE MAT independent of battery voltage or ambient light.
* **Current Calibration**:

  | Class | `OpenRound.cpp` (Sept 2026, measured on the mat) | `ObstacleRound.cpp` (earlier) |
  |:---|:---|:---|
  | ORANGE | %R > 52 AND %B < 18 | %R > 35 AND %B < 27 |
  | BLUE | %B > 23 AND %R < 40 | %B > 36 AND %R < 24 |
  | WHITE / none | neither rule matches, or $R+G+B < 100$ | neither rule matches |

  Measured on the current car: white %R 47 / %B 19, orange 69 / 11, blue 36 / 27.
* **Bench tool**: the thresholds above were captured with the colour-capture version of `src/tools/bench/tof_test.ino` (commit `a6f685e`, guide in [`tof_color_sensor_routine.txt`](../src/tools/bench/tof_color_sensor_routine.txt)). That file has since been replaced by a three-ToF test; restore the old version from git history to re-measure.
* **Why Use Channel Percentages**: Raw counts shift with LED brightness, sensor height and shadows. Normalised ratios (%R = R / (R+G+B)) are largely insensitive to overall intensity.
* **Debounce Filter**: Line detection must hold for `COLOR_CONFIRM_MS = 6 ms` before triggering corner events.

---

## 10. Pillar Color Calibration (Raspberry Pi Dashboard)

Pillar color detection runs independently on the Raspberry Pi 5:
1. Start the calibration dashboard on the Pi:
   ```bash
   cd src/pi
   python3 dashboard.py
   ```
2. Open a browser at `http://<pi-ip>:8080`.
3. Adjust the HSV sliders against the live view of red and green pillars under actual arena lighting.
4. Press **Save**: values are written atomically to [`src/pi/config.json`](../src/pi/config.json). Restart `main.py` to pick them up.

(The click-to-sample Lab tool the team also uses is not committed yet — see [`src/pi/README.md`](../src/pi/README.md).)

---

## 11. Master Calibration Constants Reference

| Firmware Constant | `OpenRound.cpp` | `ObstacleRound.cpp` | Calibration Step |
|:---|:---:|:---:|:---:|
| `TICKS_PER_CM` | **14.853** | **31.933** | Step 2 |
| `SERVO_TRUE_STRAIGHT` | **71.0°** | **69.0°** | Step 4 |
| `SERVO_MAX_LEFT` / `RIGHT` | 1.0° / 150.0° | 5.0° / 115.0° | Step 4 |
| `SERVO_SLEW` | 2.5°/cycle | 2.5°/cycle | Step 3 |
| `SIGNAL_MIN_MCPS` | — | 4.0 | Step 5 |
| `TOF_MAX_VALID_MM` | 1200 mm | 1300 mm | Step 5 |
| `TURN_KP` / `TURN_KV` | 2.5 / 3.5 | 2.5 / 3.5 | Step 6 |
| `TURN_STOP_DEG` | 0.3° | 0.3° | Step 6 |
| `TURN_MIN_PWM` / `MAX_PWM` | 100 / 130 | 100 / 130 | Step 6 |
| `HEAD_KP` / `KI` / `KD` | 2.0 / 0.0 / 0.0 | 2.0 / 0.0 / 0.0 | Step 7 |
| `YAW_FILT_ALPHA` | 0.35 | 0.35 | Step 7 |
| `BASE_SPEED` (PWM) | 70 | 150 | — |
| Floor ORANGE | %R > 52 & %B < 18 | %R > 35 & %B < 27 | Step 8 |
| Floor BLUE | %B > 23 & %R < 40 | %B > 36 & %R < 24 | Step 8 |
| `COLOR_CONFIRM_MS` | 6 ms | 6 ms | Step 8 |

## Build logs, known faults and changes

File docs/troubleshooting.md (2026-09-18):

# Field Troubleshooting Guide — Failure Modes & Verified Fixes

> A diagnostic manual documenting 10 critical hardware, electrical, optical, and kinematic faults experienced during testing, along with root causes and verified remedies.
> For a high-level system overview, return to the **[Master README](../README.md)**.

---

## Quick Diagnostic Index

| Fault Symptom | Primary Root Cause | Verified Field Remedy |
|:---|:---|:---|
| [1. False Wall Reports on Open Track](#1-the-car-reports-a-wall-that-is-not-there) | White floor reflection clipping ToF beam | Fit collimator snouts + $+2.0^\circ$ wedge; filter `SIGNAL_MIN_MCPS` |
| [2. Heading Drifts Over 3 Laps](#2-heading-drifts-over-a-run) | Gyro integration drift / turn overshoot bias | Swap to BNO085; calibrate `TURN_KP` and `SERVO_TRUE_STRAIGHT` |
| [3. Double Turn / 180° Spin at Corner](#3-the-car-turns-twice-at-one-corner) | Sensor re-crossing corner lines on exit | Increase `POST_CORNER_LOCKOUT_CM` to $50\text{ cm}$ |
| [4. Wrong-Way Turn After Avoidance](#4-after-avoiding-a-pillar-the-next-corner-goes-the-wrong-way) | Avoidance started too close to a corner | Don't start avoidance once a corner is armed and the wall is close |
| [5. Wheel Squeal & Wide Corner Exits](#5-the-car-squeals-in-corners-and-runs-wide) | Equal-angle steering scrub | Upgrade to an Ackermann linkage |
| [6. Odometry Drifts Across Sessions](#6-distance-readings-drift-over-the-session) | Loose coupler or unloaded calibration | Tighten motor grub screws; calibrate with battery and lid fitted |
| [7. Phantom Red Obstacles in Vision](#7-the-camera-sees-red-where-there-is-no-red) | Ambient light shifting orange lines into red | Re-tune color bounds in arena; raise `min_blob_area` |
| [8. Camera Device Busy / Fails to Open](#8-camera-will-not-open) | Two processes competing for `/dev/video0` | Enable systemd service conflict masking |
| [9. MCU Browns Out on Sharp Turns](#9-servo-browns-out-the-mcu) | Servo stall current pulling down logic rail | Isolate servo on dedicated 6.0V 3A buck regulator |
| [10. Intermittent Sensor Disconnects](#10-intermittent-faults-under-vibration) | DuPont friction connectors shaking loose | Replace all wiring with crimped, latched JST-XH harnesses |

---

## Detailed Failure Mode Analyses

### 1. The Car Reports a Wall That Is Not There
* **Symptom**: Front or side ToF distance suddenly drops to $150\text{–}300\text{ mm}$ while cruising down an open straight, triggering an early turn or emergency brake.
* **Root Cause**: The white mat reflects the sensor's 940 nm infrared far more strongly than the matte black walls. The chassis nose-down rake ($\approx 0.84^\circ$ at the CAD wheelbase) dips the lower edge of the ToF cone into the floor.
* **Fix**:
  1. Fit 3D-printed $2.5 \times 10 \times 20\text{ mm}$ slot collimator snouts and $+2.0^\circ$ upward wedges ([`docs/engineering_findings.md`](engineering_findings.md#1-floor-ir-crosstalk-and-optical-collimation)).
  2. In firmware, filter on signal rate (`SIGNAL_MIN_MCPS` = 4.0 MCPS, obstacle program). Note the open question in [calibration step 5](calibration.md#6-step-5-tof-floor-signal-threshold-signal_min_mcps) about whether this should reject weak or strong returns.

---

### 2. Heading Drifts Over a Run
* **Symptom**: Laps 1 and 2 are smooth and centered, but during Lap 3 the vehicle gradually veers into the outer or inner perimeter wall.
* **Root Cause Investigation**:
  1. **Sensor Quality**: Low-grade IMUs (such as raw MPU6050) suffer from thermal zero-rate drift that accumulates over 60 seconds. *Fix: Replace with an SPI-connected BNO085 running internal sensor fusion.*
  2. **Systematic Turn Bias**: A subtle $1.0^\circ$ overshoot per corner accumulates to $12.0^\circ$ of drift across 12 corners. *Fix: Run Step 6 of calibration and lower `TURN_KP` if the mean error has a consistent sign.*
  3. **Steering Asymmetry**: Left and right turns producing different mean exit errors indicate mechanical servo misalignment. *Fix: Re-run Step 4 calibration for `SERVO_TRUE_STRAIGHT`.*

---

### 3. The Car Turns Twice at One Corner
* **Symptom**: Immediately after completing a $90^\circ$ corner turn, the vehicle detects a line, executes an immediate second turn, and drives backward or into the wall.
* **Root Cause**: As the car swings out of a turn, the downward-facing TCS34725 sensor sweeps across the outer corner marker line it just cleared.
* **Fix**: Enforce an encoder-gated lockout (`POST_CORNER_LOCKOUT_CM = 50 cm`) during which all floor color triggers are suppressed.

---

### 4. After Avoiding a Pillar, the Next Corner Goes the Wrong Way
* **Symptom**: Runs without obstacles complete 12 corners flawlessly. When avoiding an obstacle on the straight leading into a corner, the car turns the opposite direction.
* **Root Cause**: The avoidance sub-machine was started just before a corner and still held a steering offset when the car reached the corner.
* **Fix**: Give corners priority. `ObstacleRound.cpp` evaluates the turn triggers first and does not enter `STATE_AVOID` once a corner line has armed the turn and the front wall is within `FRONT_TURN_MM`. Missing a pillar loses points; missing a corner ends the run.

---

### 5. The Car Squeals in Corners and Runs Wide
* **Symptom**: Audible tire scrub through corners, rubber scuff marks on the mat, wide corner exits, and inconsistent heading changes run-to-run.
* **Root Cause**: Parallelogram steering linkages force both wheels to identical steering angles. In a tight corner, the inner wheel needs a significantly tighter radius than the outer wheel; the difference forces the tires to scrub laterally.
* **Second-Order Effect**: Slipping tires cause the drive axle encoder to over-read, corrupting the lane-gap odometry correction.
* **Fix**: Upgrade to an Ackermann linkage where the steering-arm lines meet near the centre of the rear axle ([`docs/engineering_findings.md`](engineering_findings.md#3-evolution-of-three-steering-geometries)).

---

### 6. Distance Readings Drift Over the Session
* **Symptom**: `TICKS_PER_CM` was perfectly calibrated in the morning, but by afternoon straightaway distances are systematically off by several centimeters.
* **Root Cause**:
  1. Loose grub screws on the motor-to-axle gear coupler allowing microscopic shaft slip under acceleration.
  2. Performing calibration without the battery or body shell installed: tyre squash under real competition mass ($540\text{ g}$) alters the effective rolling radius.
* **Fix**: Apply blue threadlocker to all drive shaft grub screws and always calibrate at full competition mass.

---

### 7. The Camera Sees Red Where There Is No Red
* **Symptom**: The vision system registers phantom red pillars near the orange corner lines or magenta parking lot boundary limiters.
* **Root Cause**: In HSV color space, orange, red, and magenta sit in close proximity along the hue spectrum. Warm arena lighting or shadows shift the perceived hue into the red envelope.
* **Fix**: Calibrate color thresholds under actual arena lighting using the browser dashboard. Filter out contours that fall within known floor-level regions of interest, and increase `min_blob_area`.

---

### 8. Camera Will Not Open
* **Symptom**: `CameraThread` crashes with a device busy error or V4L2 resource allocation failure upon startup.
* **Root Cause**: Linux allows only one process to hold `/dev/video0`. If the calibration dashboard (`dashboard.py`) is running in the background, the autonomous runner (`main.py`) cannot access the camera.
* **Fix**: Run only one of the two at a time. [`robodash.service`](../src/pi/robodash.service) declares systemd mutual exclusion:
  ```ini
  [Unit]
  Description=Perception calibration dashboard
  Conflicts=robot.service
  ```
  (This only helps once `main.py` is also installed as `robot.service`; that unit file is not in the repository yet.)

---

### 9. Servo Browns Out the MCU
* **Symptom**: The STM32 randomly resets during sudden steering transitions and restarts from boot (`setup()`).
* **Root Cause**: Rapid servo actuation draws instantaneous current spikes of up to $2.5\text{A}$, causing voltage sags on shared power rails.
* **Fix**:
  1. Power the steering servo from a dedicated $6.0\text{V}$, $3\text{A}$ buck regulator with a $470~\mu\text{F}$ low-ESR capacitor at the servo plug.
  2. Enforce software slew rate limiting (`SERVO_SLEW = 2.5 deg/cycle`).

---

### 10. Intermittent Faults Under Vibration
* **Symptom**: Vehicle operates reliably on the bench but drops I2C communication or loses encoder counts when driving over track seams and vibration bumps.
* **Root Cause**: DuPont jumper wires depend on friction fits that loosen under chassis vibration.
* **Fix**: Mandate genuine crimped and latched JST-XH connectors with heat-shrink strain relief for all interconnects, and screw terminals with ferrules for power. Breadboards are strictly banned.

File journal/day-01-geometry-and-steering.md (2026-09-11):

# Day 01 — steering verdict, layout optimizer, locked v1 geometry (2026-07-12)

## Steering mechanism decided (evidence-based)
Compared single central pivot (turntable) vs Ackermann bell-crank vs parallel
bell-crank for the parallel park with a kinematic slop Monte-Carlo AND a pymunk
dynamic-friction sim (`src/sim/steering_study.py`, `steering_dyn.py`; plots in
`media/steering/`). Result: **single central pivot wins for parking** — equal
accuracy, ~3× better robustness to build slop (its one bearinged joint is what the
AS5600 measures), and 1 joint vs 5. Parallel bell-crank dominated → dropped.
Ackermann only pays off at higher speed / with joints built <0.3°. Full write-up:
`journal/steering-study-2026-07-12.md`. Decision #4 reaffirmed with the evidence.

## Layout optimizer (objective: lowest CG / most stable)
`src/sim/optimize_layout.py` swept track / wheelbase / wheel-dia over 455 feasible
designs against WRO rules, BOM+PLA mass, turn radius, parking-bay fit, and fisheye
camera coverage. Key findings:
- Tip-stability is huge everywhere (55°+), so the car cannot roll at parking speed —
  stability is NOT the binding constraint; parking-width margin is. So track is set
  to a balanced 120 mm, not the raw optimum 140 mm.
- **The MG996R servo on the deck is 28% of the CG moment — the #1 CG driver.** Mount
  it LOW. Pi 4B is #2 (18%). Battery-in-front-of-motor (80 g, low) is good — keep it.
- A 160° fisheye covers the 1 m lane a car-length ahead trivially; camera height is
  set only by clearing the component stack (~90 mm mast), ~free in CG terms.
- Estimated mass ~450 g (BOM + PLA at ~35% effective infill) — far under 1.5 kg.

## Discrepancies vs prev design "WRo final v5"
- Its 165×80 footprint is very NARROW (80 mm track) → tippy end of range. Widened.
- Its mass readout was default-Steel (fake ~2 kg). Assign real materials for a true number.
- Servo in the model was MG996R (correct) not the earlier-noted MG90S — records fixed.

## LOCKED v1 geometry (now in SPECSHEET §3 + Fusion global parameters)
track 120 · wheelbase 128 (R=128) · wheel_dia 40 · lock ±45° · L×W×H 175×138×95 ·
~450 g · CG ~28 mm · camera mast ~90 mm. Layout figures: `media/steering/`.

## Tooling note
PyBullet could not be installed here (no prebuilt wheel, no MSVC C++ toolchain, no
winget). Dynamics done in pymunk instead — correct tool for this geometry/mass
question anyway; a full rigid-body engine would not change the verdict.

## Next
Shanto models the chassis + steering in Fusion against the locked parameters. Then:
confirm encoder count, assign real materials for true mass/CG, verify the bell-crank
link delivers ±45° without a toggle point, and test on the real mat.

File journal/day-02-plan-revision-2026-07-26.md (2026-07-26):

# Day 02 — as-built revision, electrical architecture, two blocking findings (2026-07-26)

The car has been built, and it diverges from the 2026-07-12 design in four significant
ways. This entry records the divergence, the reasons, and two problems the build exposed
that the design phase had not anticipated.

Nothing from the original design has been deleted. Every conflict is marked
**SUPERSEDED** with a dated block in `DECISIONS.md`, and the superseded reasoning stays
visible above it. A repository that shows *why* a design changed is stronger evidence of
engineering than one that only ever shows the final answer.

---

## 1. What changed from design to build

| Item | Designed 2026-07-12 | Built | Record |
|---|---|---|---|
| Steering | single central pivot + AS5600 closed loop | **parallelogram tie-bar, open-loop** | Decision #4 superseded, #15, #16 |
| Geometry | track 120 / WB 128 / 175×138×95 / wheel 40 | **track 105 (115 outer) / L 165 / wheels 46 F, 50 R** | SPECSHEET §3 |
| Distance sensor | VL53L1X ×5 | **VL53L0X ×5** | Decision #7 corrected, #18 |
| Turn trigger | front wall distance | **TCS34725 floor colour** | Decision #1 amended, #17 |
| Reduction | none specified | **5:1 to solid rear axle** | Decision #14 confirmed |
| Motor driver | TBD | **BTS7960** | Decision #22 |
| IMU | TBD | **MPU9250 on SPI** | Decision #20 |

---

## 2. Why parallelogram, when the simulation said otherwise

`journal/steering-study-2026-07-12.md` ranked parallel bell-crank as *strictly dominated*
and locked the single central pivot. The build went the other way.

**The reason, from assembly:** a central pivot rotates the whole front beam about one
axis, so during a turn one front wheel swings forward and the other swings back. The
car's effective length grows exactly when clearance is tightest.

**Quantified.** Each front wheel translates fore/aft by `(track / 2) × sin δ`. At the
as-built track of 105 mm and the measured 35° lock:

```
(105 / 2) × sin 35° = 30.1 mm per wheel
```

Against a parking bay of 1.5 × 165 mm = 247.5 mm with **82.5 mm of total longitudinal
slack**, that is **36% of the slack consumed for zero navigational benefit** — in a rule
where touching a magenta limitation scores 0 parking points (rule 9.24.7).

**The study was not wrong within its own objective function; the objective function was
incomplete.** `src/sim/steering_study.py` scored kinematic scrub, parking accuracy and
robustness to build slop. It never modelled the **swept envelope of the vehicle body
during a turn**. That missing term is the whole reason it ranked parallel bell-crank as
dominated. The build found the term the model was missing.

**Costs accepted and recorded:** 4+ linkage joints instead of 1 (against Decision #10's
novice-assembler principle); no AS5600, so **steering is fully open-loop**; equal-angle
steering, so scrub is unchanged from the turntable — a parallelogram is *not* Ackermann;
and **turn radius R is nominal, not measured**.

**Why it is still sound:** the loop is closed on *vehicle heading* by the IMU, not on
steering angle. Steering only has to be monotonic and repeatable, not accurate. This is
the same argument that already lets Decision #1 terminate turns on measured heading.

---

## 3. FINDING 1 — the VL53L0X has no ROI, so floor rejection must be mechanical

The 2026-07-12 ToF override assumed a VL53L1X, whose programmable SPAD ROI can narrow the
beam in firmware. **The parts on hand are VL53L0X: fixed ~25° FoV, no ROI.** That
mitigation does not exist on this part.

This matters because of the field colours: the mat is white (rule 13.2) and both exterior
and interior walls are black on every visible face (rules 13.4, 13.6). **The false target
reflects near-infrared better than the true target.** A naive closest-return read locks
onto the floor. This is the concrete form of the original "ToF randomly false-detects the
floor" objection that Decision #7 overrode.

`electrical/collimator.py` solves it. With `d_floor = h / tan(θ_eff)` and a side wall at
(1000 − 115)/2 = 442.5 mm:

| Configuration | θ_eff | d_floor @ h = 40 mm | Margin |
|---|---|---|---|
| Bare VL53L0X | 13.56° | 166 mm | −277 mm ✗ |
| Snout only | 4.63° | 494 mm | +51 mm — too thin |
| **Snout + 2° wedge** | **2.63°** | **870 mm** | **+428 mm ✓** |

**Spec: printed collimator snout, slot 2.5 mm tall × 10 mm wide × 20 mm deep, plus a +2°
upward mounting wedge, on all five sensors.** The slot is wide rather than round because
the L0X emitter and receiver apertures sit ~2.5 mm apart and a round hole vignettes the
receiver.

**The wedge is not decoration.** Front wheels are 46 mm and rear wheels are 50 mm, so the
chassis sits nose-down by `atan(2 / wheelbase)` ≈ **1.0–1.1°**, and every chassis-mounted
sensor inherits that — aimed at the floor. Without correction the margin drops to +51 mm,
which is not a margin.

**Duty split (Decision #19):** L90/R90 handle open-corridor centring at 442.5 mm.
FL30/FR30 handle obstacle-corridor centring when threading a pillar-to-wall gap, where
slant range = gap ÷ sin 30° = 2 × gap — a 150 mm gap reads at 300 mm, a 350 mm gap at
700 mm. They degrade exactly when the gap is wide, which is when L90/R90 take over. That
is a designed split of duties, not a limitation.

**Highest-risk open item in the build.** Bench-test signal rate against black MDF with
the snout fitted, at 442 mm and at 300/700 mm at 60° incidence, **before printing five
mounts**. The aperture throws away photons and the wall is already a poor NIR target. If
signal rate is marginal, the Sharp GP2Y0A21 fallback must be ordered immediately — and
its lead time is still unrecorded.

---

## 4. FINDING 2 — the two-arc parallel park is not feasible, and the problem is scale-invariant

`src/sim/park_feasibility.py` was written to prove the reverse two-arc park carried in
SPECSHEET since 2026-07-12. It disproves it.

The solver sweeps the parked longitudinal position — the only free variable in a
symmetric two-arc at fixed lock — and checks the swept body polygon against both
200 × 20 × 100 mm magenta limitations and the outer wall. The car is 50–90 mm tall and the
limitations are 100 mm tall, so it **cannot pass over them** at any point.

| Lock | R | R/L | Best clearance | Verdict |
|---|---|---|---|---|
| **35° (as built)** | 157 mm | 0.95 | **−25.6 mm** | **COLLISION** |
| 40° | 131 mm | 0.79 | −10.8 mm | COLLISION |
| 45° | 110 mm | 0.67 | +0.1 mm | clears by nothing |
| 60° | 64 mm | 0.38 | +0.5 mm | clears by nothing |

The failure mode is specific: the **front-outer corner** sweeps into the entry limitation
at ~37° heading, while the rear axle is still 164 mm along the bay. The rear clears; the
front does not.

**The problem is scale-invariant, which is the important part.** The bay is always
1.5 × car length, so the slack is always 0.5 × car length. **Shortening the car does not
help — the bay shrinks with it.** The only levers are the ratio **R/L** and the manoeuvre
strategy. A symmetric two-arc needs roughly R/L ≤ 0.7; the as-built car is at 0.95.

Raising the lock to 45° would reach R/L = 0.67 and clear by ~0.1 mm. That is not a margin,
and it is worthless with open-loop steering.

**Decision: the primary parking manoeuvre becomes a multi-point (3+) shuffle, closed on
IMU yaw** (Decision #21 amended). Enter at whatever angle the geometry allows, then
shuffle forward and back to straighten. Slower, but robust to R error — which matters
precisely because there is no steering feedback. Parking is 15 pts plus 7 pts for
finishing in the start section: **22 of 122**, so this is worth the time cost.

---

## 5. Electrical architecture

Written up in full in `electrical/ELECTRICAL.md`; block diagram in
`schemes/wiring_block_diagram.png` (`schemes/` was previously empty, which scores 0 on
rubric Criterion 2).

Two points worth calling out here:

**The 0x29 collision.** The VL53L0X and the TCS34725 both ship at I²C address 0x29, and
the TCS has neither a shutdown pin nor an address strap. During ToF enumeration each
sensor briefly appears at 0x29, so every enumeration write would also hit the colour
sensor. The buses are therefore split: five ToFs alone on I²C1 with XSHUT reassignment to
0x30–0x34, the TCS alone on I²C2, and the MPU9250 moved to SPI. This also isolates the
turn trigger — the most critical sensor in the Open round — from any ToF cable fault.

**The Open-round claim is physical, not a flag.** The Pi 4B and BEC-C are on a separate
harness that is unplugged for the Open Challenge. A judge can verify that the Open
configuration cannot be influenced by the Pi because the Pi is not electrically present.

---

## 6. The 5:1 reduction is the highest-value change in the build

| | Ungeared | With 5:1 |
|---|---|---|
| Top speed | 2.79 m/s | **0.70 m/s** |
| Odometry | 0.70 mm/count | **0.175 mm/count** |
| 20 mm line dwell | 7.2 ms | **28.6 ms** |

It converted three separate problems — uncontrollable speed, coarse odometry, and an
unreadably short colour-line window — into non-problems at once.

---

## 7. Still open

| # | Item | Blocks | Age |
|---|---|---|---|
| 1 | **BD national competition date** | all three commit deadlines | since 2026-07-12 |
| 2 | Wheelbase, front axle centre to rear axle centre | R, park solver | new |
| 3 | Encoder counts per motor rev (hand-rotate) | odometry constant | since 2026-07-12 |
| 4 | MPU9250 `WHO_AM_I` (0x71 / 0x70 / 0x73) | IMU driver | new |
| 5 | VL53L0X breakout — regulator + level shifters? | I²C pull-up rail | new |
| 6 | 25GA stall current | power budget in the journal | since 2026-07-12 |
| 7 | Sharp GP2Y0A21 lead time | ToF fallback path | since 2026-07-12 |

**Item 1 is the critical one.** It gates the first commit deadline (≥2 months pre-event,
≥1/5 of code). `src/` currently contains four simulation studies and **no firmware**.
Everything in this revision is documentation, which does not count as code.

---

## 8. Next

1. Measure the wheelbase; re-run `park_feasibility.py` and lock the parking strategy.
2. Bench-test VL53L0X signal rate against black MDF **before printing five snouts**.
3. Hand-rotate the encoder and close the odometry constant.
4. Get the national date, then schedule firmware against the three commit gates.
5. Begin firmware: HAL bring-up, ToF enumeration, IMU heading integrator, TCS edge
   detector with lockout and direction decode.

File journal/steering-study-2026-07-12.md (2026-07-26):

# Steering mechanism study — which is most robust for a full parallel park (2026-07-12)

**Question:** single central pivot vs a two-knuckle linkage — which gives the most
robust, repeatable full parallel park? Decided with a kinematic + joint-slop
Monte-Carlo model, not opinion. Code: `src/sim/steering_study.py`. Plots: `media/steering/`.

**Method.** 4-wheel kinematic model at v1 geometry (wheelbase L=120, front track
T=95 mm, target R≈130). Each mechanism is *calibrated* first — its outer loops
(gyro heading-hold + encoder distance + AS5600 angle) null the nominal bias, which
is what actually happens on the car — then stressed with Monte-Carlo joint slop
(200k reverse two-arc parks each). Metric = 95th-percentile lateral parking error
(curb-side wheels must finish within 20 mm of the wall to score "parallel").

## Candidates
- **TT** — Turntable / single central pivot: rigid front axle, both wheels equal angle, **1 pivot joint**. AS5600 on the pivot sees the true axle angle.
- **PAR** — Parallel bell-crank: 2 kingpin knuckles + tie-rod, equal angles, **~5 joints**.
- **ACK** — Ackermann bell-crank: 2 kingpin knuckles, arms angled for Ackermann, **~5 joints**.

## Results
**1. Scrub (tyre fighting) — the tight-turn penalty of equal-angle steering.**
At the tight radii a parallel park needs (R/T ≈ 1.5), forcing both front wheels to
the same angle scrubs badly:

| Commanded centre angle | TT / PAR scrub | ACK scrub |
|---|---|---|
| 20° | 2.5° | 0° |
| 40° (full lock) | **8.4°** | **0°** |
| 45° | 10.1° | 0° |

Realized turn radius at 40° lock: TT/PAR = 167 mm, ACK = 143 mm. Ackermann removes
scrub entirely by giving the inner wheel 51.5° and the outer 32.2°.

**2. Robustness to joint slop (95th-pct lateral park error).**
- **TT: 1.76 mm, essentially slop-independent** — its one bearinged pivot is what the AS5600 measures, so there is almost no *unobserved* slop.
- **ACK/PAR: error grows linearly with unobserved downstream slop** (the 2 link ball-joints + kingpin per wheel that the central AS5600 cannot see). They beat TT only when downstream slop is below **~0.22°**; at 0.5° → 3.7 mm, at 1.0° → 7.4 mm. All stay under the 20 mm "parallel" limit until slop ≈ 2.6°.

**3. Parallel bell-crank is strictly dominated** — it carries TT's full 8.4° scrub
*and* ACK's 5-joint slop exposure. No reason to build it. Drop it.

## Honest caveat (reads in ACK's favour)
The Monte-Carlo *calibrates out* TT's nominal scrub bias, so TT's 1.76 mm is
optimistic. In reality 8° of front-wheel scrub is friction- and surface-dependent,
is not perfectly repeatable, and makes the drive wheels slip — which corrupts
*odometry*, the very thing parking distance control relies on. So TT's true
repeatability is worse than 1.76 mm, and the 0.22° crossover *understates*
Ackermann's real advantage.

## Verdict
1. **Drop Parallel bell-crank** (dominated).
2. **Build Ackermann bell-crank as the v1 target** — it is the only option with zero
   scrub, and scrub is itself a randomness source the "no-randomness" spec should
   reject. Your existing CAD (two bearing knuckles + tie-rod) is already the right
   hardware; it needs (a) the steering arms angled for Ackermann, (b) a stiff
   tie-rod (not the 3 mm flat plate), (c) bearinged/preloaded joints.
3. **Earn it mechanically.** Ackermann only wins if downstream slop is kept low.
   Targets: bearinged kingpins, zero-backlash (preloaded or flexure) links, tie-rod
   stiff in bending/torsion, and mount the AS5600 to read a **knuckle** (or as close
   to the wheels as possible) so more slop is *observed* by the loop. Budget:
   **downstream slop < 0.3–0.5°.**
4. **Fallback gate (measure, don't guess):** print the mechanism, measure actual
   backlash at the wheel. If you cannot get under ~0.5°, fall back to the turntable
   (slop-immune, novice-proof) and accept the scrub. Decision is made on a measured
   number, on the bench.

## Build numbers to model in Fusion
- Ackermann steering-arm angle (knuckle arm pointing at rear-axle centre):
  `atan((T/2)/L) = atan(47.5/120) ≈ 21.6°`.
- Full-lock wheel angles to hit R=143 mm: inner **51.5°**, outer **32.2°**.
- Keep sensors/camera on the fixed chassis (unchanged rule).

## Optional follow-up
A full rigid-body sim (PyBullet/MuJoCo) would add tyre-friction and tip dynamics,
but it will not change this geometry verdict — it would only further penalise TT's
scrub. Worth doing later only if we want to tune drive speed/traction, not to
decide the mechanism.

---

# Dynamic validation (pymunk 2D rigid-body) — added 2026-07-12

PyBullet would not build on the dev machine (no MSVC C++ toolchain; no prebuilt
wheel for Python 3.10/Win64). Used **pymunk** instead (2D rigid-body, installs as a
binary wheel). Top-down car, each tyre applies a lateral grip impulse capped by
friction (mu * load); when a mechanism demands more side force than the tyre can
give (scrub), the tyre SLIPS — the effect the kinematic model idealised away.
Code: `src/sim/steering_dyn.py`. Plot: `media/steering/4_dynamics.png`.

**Test:** reverse two-arc park; sweep surface friction mu = 0.6–1.2; inject built
joint slop (TT 0.15° correlated, ACK 0.5° per wheel). Metric = how far the parked
position wanders with surface (bias, calibratable) and run-to-run (slop, not).

**Results:**
- Surface-friction sensitivity: **TT 2.7 mm vs ACK 2.9 mm span — essentially equal.**
  At parking speed the turntable's 8° scrub does NOT become a large path error; the
  tyres absorb it as small distributed slip. Scrub is cheap at low speed.
- Run-to-run scatter from build slop (@0.5°): **TT 0.42 mm vs ACK 1.25 mm** — the
  single pivot is ~3× tighter, because its one bearinged joint is what the AS5600
  measures (nothing unobserved).

**This revises the kinematic verdict.** The kinematic model overstated Ackermann by
treating scrub as a hard error. Under real low-speed dynamics, scrub barely matters
and build-slop robustness dominates.

## Combined verdict (kinematic + dynamic)
- **For the parallel park (low speed): single central pivot / turntable WINS** —
  equal accuracy, ~3× better robustness to build slop, and 1 joint vs 5 (decisive
  for a novice assembler). This **vindicates the originally-locked Decision #4.**
- **Ackermann's zero-scrub only clearly pays off at higher speed** (open/obstacle
  laps, lateral force ∝ v²/R, tyres saturate) — NOT YET SIMULATED. It also only
  beats the pivot on slop if downstream joints are built to <~0.2–0.3°.
- **Parallel bell-crank: still dominated. Drop it.**

## Recommendation
Keep **single central pivot** locked for v1 (Decision #4 stands, now evidence-backed
for parking). Before finalising, optionally simulate a HIGH-SPEED corner to see if
scrub costs enough on the speed laps to justify Ackermann's extra joints. If built,
Ackermann must hit <0.3° downstream slop and mount the AS5600 on a knuckle.

## Caveats (honesty)
Both sims use assumed numbers (mass split, mat mu, drive authority, 0.5° slop). The
qualitative conclusions (low-speed scrub is cheap; single pivot is slop-robust) are
solid; exact mm values are not gospel. Real decision is confirmed on the mat.

---

## ⚠️ SUPERSEDED — 2026-07-26

**This study's conclusion was not followed.** The car was built with **parallelogram
(equal-angle tie-bar) steering**, which this study ranked as "strictly dominated".

**The study was not wrong within its own objective function — the objective function was
incomplete.** It scored candidates on kinematic scrub, parking accuracy and robustness to
build slop. It **never modelled the swept envelope of the vehicle body during a turn.**

That missing term is decisive. On a single central pivot the whole front beam rotates
about one axis, so one front wheel swings forward and the other swings back by
`(track/2) × sin δ`. At the as-built track of 105 mm and a 35° lock that is
**±30.1 mm per wheel** — the car's effective length grows exactly when clearance is
tightest. Against a parking bay of 1.5 × 165 mm = 247.5 mm with only **82.5 mm of total
slack**, that is **36% of the slack consumed for zero navigational benefit**, in a rule
where touching a magenta limiter scores 0 parking points (rule 9.24.7).

**Nothing above this line has been edited.** The study, its plots and its conclusion are
preserved deliberately: a repo that shows "we simulated three mechanisms, chose one,
built another, and here is the term the model was missing" is stronger evidence of
engineering than one that only ever shows the winner.

Superseding record: `DECISIONS.md` #4 supersession block, #15, #16;
`journal/day-02-plan-revision-2026-07-26.md`.

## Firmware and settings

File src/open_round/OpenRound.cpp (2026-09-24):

#include <Arduino.h>
#include <Servo.h>
#include <SPI.h>
#include <Wire.h>
#include <SparkFun_BNO08x_Arduino_Library.h>
#include <Adafruit_TCS34725.h>

// ============================================================
// OPEN ROUND - NON-BLOCKING FIRMWARE  (LiDAR revision)
//
// Distance now comes from a Raspberry Pi over USB serial instead of
// ToF sensors. The Pi sends one line per frame:  left,front,right
// in millimetres. That same Serial is the debug channel, so FSM logs
// go back to the Pi - prints are state-transition only, never per-loop.
//
// PER CORNER  (LiDAR only - the colour sensor plays no part while the
// LiDAR is alive; it only lights LED2 / LED3)
//   1. drive straight on IMU heading
//   2. turn fires when a side beam reads above SIDE_OPEN_MM (1500) for
//      SIDE_OPEN_FRAMES consecutive NEW LiDAR frames (the inner wall has
//      given way). Until the direction is known BOTH sides are watched and
//      the side that opens first locks it: right = clockwise, left =
//      anticlockwise (both at once: the longer beam). After that only the
//      inner side is watched.
//   3. FALLBACK: the front beam below FRONT_TURN_MM (200) turns anyway
//      (direction not known yet: toward the longer side beam). Past the
//      post-corner lockout this replaces the wall-panic RECOVER on a straight.
//   4. eased 90 deg arc at full steering lock, then straight back to
//      DRIVE on the new heading (no lane correction - IMU only)
//
// WHY 1500 mm IS SAFE AS A FIXED NUMBER
// The widest corridor is 1000 mm, so the inside wall can never read
// more than ~1000 mm mid-straight. Past the end of the inner wall the
// side beam looks down the next straight, well beyond 1500 mm.
//
// STOPPING WHERE IT STARTED
// At START the front beam's distance to the wall ahead is remembered
// (median of the last 5 frames while standing). After turn 12 the car
// drives the start straight until the front beam is back near that value
// (encoder L - A only bounds it), then ALIGNS: creeps forward / backward
// at ALIGN_PWM until the front is within FRONT_DEADBAND_MM of the start
// value on a settled (stopped) reading. No usable front at START (beyond
// the LiDAR's 3.5 m, or LiDAR dead) -> the old encoder L - A stop.
//
// DEGRADED MODE
// No LiDAR frame for 1000 ms sets lidarDead. Only then does the colour
// line trigger turns (and set the direction if it is still unknown:
// orange = clockwise) - with no LiDAR there is no side or front beam, and
// the car would drive into the outer wall.
//
// STARTUP SEQUENCE
//   1. Boot: onboard LED (PC13) slow-blinks. loop() only polls Serial -
//      the start button is ignored until the Pi's first well-formed
//      LiDAR frame arrives.
//   2. First frame received: onboard LED goes SOLID. The FSM enters
//      WAIT_START and waits for the start button on PB12.
//   3. Button pressed (debounced): car starts driving immediately.
// The button must be seen RELEASED before a press counts, so a button
// held (or shorted) at power-up can never launch the car.
//
// BUTTON (PB12) DURING AND AFTER A RUN
//   running  -> press: PAUSE (motor off, everything frozen where it is)
//   paused   -> press: RESUME exactly where it stopped (mid-straight,
//               mid-turn or mid-recovery)
//   finished -> press: a fresh 3-lap run (put the car back in the start
//               section first)
// Presses closer than BTN_LOCKOUT_MS are ignored (bounce, double taps).
//   status LED: slow blink 250 ms while paused
//
// STATUS LED (onboard PC13, active LOW)
//   slow blink 500 ms  waiting for the Pi's first LiDAR frame
//   solid              Pi connected, LiDAR live (ready / running / finished)
//   fast blink 100 ms  LiDAR frames stale (Pi dropped out)
//
// BENCH-VERIFIED
//   motor    PA2 forward, PA3 reverse
//   encoder  TIM5 PA0/PA1, negated so forward counts up
//   IMU      BNO08x SPI1 ~100 Hz, clockwise = negative yaw
//   colour   TCS34725 CH4, white pR 47 / orange pR 69 / blue pB 27
//   servo    500-2500 us, straight 76.5, left stop 20, right stop 140
//            turning radius at full lock: left 27 cm, right 25 cm
// ============================================================

enum BlockColor { COLOR_NONE, COLOR_ORANGE, COLOR_BLUE };

enum RobotState {
  STATE_WAIT_START,
  STATE_DRIVE_TO_CORNER,
  STATE_TURNING,
  STATE_FINAL_STRAIGHT,
  STATE_RECOVER,
  STATE_FINISHED,
  STATE_PAUSED               // button pause: resumes the state it interrupted
};

// ============================================================
// HARDWARE PINS & OBJECTS
// ============================================================
const int MOT_RPWM_PIN = PA2;     // forward  (TIM2_CH3; TIM5 is the encoder)
const int MOT_LPWM_PIN = PA3;     // reverse  (TIM2_CH4)
const int SERVO_PIN    = PA8;

const int IMU_CS_PIN  = PA4;
const int IMU_INT_PIN = PB0;
const int IMU_RST_PIN = PB1;

const int STATUS_LED_PIN = PC13;  // Black Pill onboard LED, active LOW - see STATUS LED above
const int LED2_PIN = PB13;        // lit while ORANGE is under the sensor
const int LED3_PIN = PB14;        // lit while BLUE is under the sensor
const int BTN_START_PIN = PB12;   // start button to GND, internal pull-up (pressed = LOW)

#define I2C_SCL     PB6
#define I2C_SDA     PB7
#define TCA_RST_PIN PB8
#define TCA_ADDR    0x70
#define TCS_CH      4             // TCS34725

// ---- calibration ----
const float TICKS_PER_CM        = 14.853;

const int   SERVO_MIN_PULSE_US  = 500;
const int   SERVO_MAX_PULSE_US  = 2500;
const float SERVO_TRUE_STRAIGHT = 76.5;
const float SERVO_MAX_LEFT      = 20.0;   // left hard stop  (below straight steers LEFT)
const float SERVO_MAX_RIGHT     = 140.0;  // right hard stop (above straight steers RIGHT)
const float IMU_YAW_SIGN        = 1.0;    // clockwise reads negative

const int BASE_SPEED     = 70;
const int CORRECTION_PWM = 55;

const unsigned long BTN_DEBOUNCE_MS = 30;
const unsigned long BTN_LOCKOUT_MS  = 400;   // ignore a second press this soon after one

SPIClass SPI_IMU(PA7, PA6, PA5);  // MOSI, MISO, SCLK
Servo steeringServo;
BNO08x myIMU;
Adafruit_TCS34725 tcs = Adafruit_TCS34725(TCS34725_INTEGRATIONTIME_2_4MS, TCS34725_GAIN_16X);

bool  tcsOk = false;
float initialYawOffset = 0.0;

// ---- onboard status LED (PC13 sinks current: LOW = on) ----
void statusLed(bool on) { digitalWrite(STATUS_LED_PIN, on ? LOW : HIGH); }
void statusBlink(unsigned long periodMs) { statusLed((millis() / periodMs) & 1); }

// ---- start button, non-blocking debounce ----
// btnStable starts as LOW ("pressed") on purpose: the first debounced
// edge we can see is therefore a RELEASE, and only the press after that
// returns true. A button held down at boot cannot start the car.
bool          btnLastRaw  = LOW;
bool          btnStable   = LOW;
unsigned long btnChangeMs = 0;

unsigned long btnLastPressMs = 0;
bool          btnPressedOnce = false;
bool          btnPress       = false;  // set by loop() once per pass: a new press happened

bool startButtonPressed() {          // true once, on the debounced press edge
  bool raw = digitalRead(BTN_START_PIN);
  if (raw != btnLastRaw) { btnLastRaw = raw; btnChangeMs = millis(); }
  if (raw != btnStable && millis() - btnChangeMs >= BTN_DEBOUNCE_MS) {
    btnStable = raw;
    if (btnStable == LOW) {
      if (btnPressedOnce && millis() - btnLastPressMs < BTN_LOCKOUT_MS) return false;
      btnPressedOnce = true;
      btnLastPressMs = millis();
      return true;
    }
  }
  return false;
}

// ============================================================
// LiDAR OVER SERIAL   "left,front,right\n"  in mm
// ============================================================
// Two thresholds on purpose. STALE (short) just stops us acting on old
// distances. DEAD (long) is what switches the car to colour-only turning -
// a single dropped batch of frames must not be read as "lidar gone" and
// fire an instant turn mid-straight.
const unsigned long LIDAR_STALE_MS      = 200;
const unsigned long LIDAR_DEAD_MS       = 1000;
const uint16_t      LIDAR_MAX_VALID_MM  = 3500;   // mat diagonal
const uint16_t      LIDAR_FAR           = 9999;   // internal "nothing there"

// A beam with no return must read FAR, never near. If a dropout were
// treated as 0 mm the wall-panic recovery would latch on permanently.
uint16_t lidarSanitize(long v) {
  if (v <= 0 || v > (long)LIDAR_MAX_VALID_MM) return LIDAR_FAR;
  return (uint16_t)v;
}

uint16_t      lidarL = LIDAR_FAR, lidarF = LIDAR_FAR, lidarR = LIDAR_FAR;
unsigned long lidarLastMs = 0;
bool          lidarStale  = true;
bool          lidarDead   = true;
uint32_t      lidarFrames = 0;
bool          lidarNewFrame = false;   // true only on the loop a frame was parsed

char    lidarBuf[40];
uint8_t lidarLen = 0;

void serviceLidar() {
  while (Serial.available()) {
    char c = Serial.read();
    if (c == '\n' || c == '\r') {
      if (lidarLen > 0) {
        lidarBuf[lidarLen] = '\0';
        char *c1 = strchr(lidarBuf, ',');
        char *c2 = c1 ? strchr(c1 + 1, ',') : NULL;
        if (c1 && c2) {
          *c1 = '\0'; *c2 = '\0';
          lidarL = lidarSanitize(atol(lidarBuf));
          lidarF = lidarSanitize(atol(c1 + 1));
          lidarR = lidarSanitize(atol(c2 + 1));
          lidarLastMs = millis();
          lidarStale  = false;
          lidarDead   = false;
          lidarFrames++;
          lidarNewFrame = true;
        }
        lidarLen = 0;
      }
    } else if (lidarLen < sizeof(lidarBuf) - 1) {
      lidarBuf[lidarLen++] = c;
    } else {
      lidarLen = 0;                 // overflow - drop and resync on newline
    }
  }
  unsigned long age = millis() - lidarLastMs;
  if (age > LIDAR_STALE_MS) lidarStale = true;
  if (age > LIDAR_DEAD_MS)  lidarDead  = true;
}

// ---- turn trigger tuning ----
const uint16_t SIDE_OPEN_MM     = 1500;  // turn side above this = inner wall gone
const uint8_t  SIDE_OPEN_FRAMES = 3;     // consecutive NEW frames before believing it
const uint16_t FRONT_TURN_MM    = 200;   // fallback: front closer than this = turn anyway

uint8_t sideOpenCount = 0;               // left + right counts are kept separately:
uint8_t sideOpenL = 0, sideOpenR = 0;    //   the first to open locks the direction

// ---- wall recovery ----
const uint16_t WALL_PANIC_MM     = 200;
const uint16_t WALL_CLEAR_MM     = 350;
const int      RECOVER_PWM       = 90;
const float    RECOVER_MAX_CM    = 30.0;
const int      RECOVER_MAX_TRIES = 3;

// ============================================================
// RUN CONSTANTS
// ============================================================
const int   TARGET_CORNERS      = 12;
const int   FINAL_STRAIGHT_CM   = 100;
const float SEARCH_SAFETY_CM    = 400.0;
const float POST_CORNER_LOCKOUT_CM = 50.0;

// ---- stop at the start position (front beam) ----
const uint16_t FRONT_DEADBAND_MM  = 20;     // done when |front - start front| <= this
const uint16_t FRONT_SLOW_MM      = 150;    // hand over to ALIGN this far before the target
const int      ALIGN_PWM          = 50;     // creep speed both ways (raise if the car won't move)
const unsigned long ALIGN_SETTLE_MS  = 300; // stopped this long before a reading counts (~3 revs)
const unsigned long ALIGN_TIMEOUT_MS = 6000;// give up aligning, stop where it is
const float    FRONT_WINDOW_CM    = 60.0;   // front stop only once encoder >= L - A - this
const float    FRONT_BACKSTOP_CM  = 60.0;   //   and never drive past L - A + this blind

uint16_t frontHist[5] = { LIDAR_FAR, LIDAR_FAR, LIDAR_FAR, LIDAR_FAR, LIDAR_FAR };
uint8_t  frontHistIdx = 0;
uint16_t startFrontMm = LIDAR_FAR;          // LIDAR_FAR = unknown -> encoder stop

uint16_t frontMedian() {
  uint16_t v[5];
  for (int i = 0; i < 5; i++) v[i] = frontHist[i];
  for (int i = 1; i < 5; i++)                       // insertion sort, 5 values
    for (int j = i; j > 0 && v[j] < v[j - 1]; j--) { uint16_t t = v[j]; v[j] = v[j - 1]; v[j - 1] = t; }
  return v[2];
}

float firstSegmentCm      = 0.0;
float fullStartStraightCm = 0.0;
bool  haveFullStraight    = false;
float finalDistanceCm     = FINAL_STRAIGHT_CM;

// ============================================================
// FSM DATA
// ============================================================
// The FSM (and its WAIT_START button wait) is held off entirely until the
// Pi has sent at least one well-formed frame - see the gate at the top
// of loop(). Everything below still initialises to its normal idle
// values; it just doesn't get ticked until fsmStarted flips true.
bool fsmStarted = false;

RobotState    currentState = STATE_WAIT_START;
bool          entered = false;
unsigned long phaseT0 = 0;

bool       dirLocked     = false;      // direction known (first corner turned)
bool       clockwiseMode = true;
int        cornerCount   = 0;

float targetHeading = 0.0;
float laneHeading   = 0.0;


// cached IMU, refreshed every loop
bool          gImuFresh = false;
float         gHeading  = 0.0;
float         gYawRate  = 0.0;
float         gPrevH    = 0.0;
unsigned long gPrevHT   = 0;

// cached colour, refreshed every loop
BlockColor gRawColor = COLOR_NONE;

// ============================================================
// HELPERS
// ============================================================
float wrapDeg(float angle) {
  while (angle > 180.0)  angle -= 360.0;
  while (angle < -180.0) angle += 360.0;
  return angle;
}

void tcaselect(uint8_t channel) {
  if (channel > 7) return;
  Wire.beginTransmission(TCA_ADDR);
  Wire.write(1 << channel);
  Wire.endTransmission();
}

void resetTCA() {
  pinMode(TCA_RST_PIN, OUTPUT);
  digitalWrite(TCA_RST_PIN, LOW);
  delay(10);
  digitalWrite(TCA_RST_PIN, HIGH);
  delay(10);
}

void setMotorSpeed(int speed) {
  speed = constrain(speed, -255, 255);
  if (speed > 0)      { analogWrite(MOT_RPWM_PIN, speed); analogWrite(MOT_LPWM_PIN, 0); }
  else if (speed < 0) { analogWrite(MOT_RPWM_PIN, 0);     analogWrite(MOT_LPWM_PIN, -speed); }
  else                { analogWrite(MOT_RPWM_PIN, 0);     analogWrite(MOT_LPWM_PIN, 0); }
}

float lastServoCmd = SERVO_TRUE_STRAIGHT;

void setServoAngle(float angleDeg) {
  angleDeg = constrain(angleDeg, SERVO_MAX_LEFT, SERVO_MAX_RIGHT);
  lastServoCmd = angleDeg;
  int pulse = (int)((angleDeg / 180.0) * (SERVO_MAX_PULSE_US - SERVO_MIN_PULSE_US)) + SERVO_MIN_PULSE_US;
  steeringServo.writeMicroseconds(pulse);
}

// TIM5 encoder, negated so driving forward counts up
void zeroEncoder() { TIM5->CNT = 0; }
long readEncoder() { return -(int32_t)TIM5->CNT; }
long absEnc(long v) { return v < 0 ? -v : v; }

// Which way are we turning, and therefore which side should open?
// Clockwise means the inner block is on the right, so the RIGHT side
// gives way at the corner. Counter-clockwise, the left.
bool turnIsClockwise() { return clockwiseMode; }   // valid once dirLocked
uint16_t turnSideMm() { return turnIsClockwise() ? lidarR : lidarL; }

// ---- IMU ----
float readYaw() {
  float qI = myIMU.getQuatI(), qJ = myIMU.getQuatJ();
  float qK = myIMU.getQuatK(), qReal = myIMU.getQuatReal();
  if (qI == 0.0f && qJ == 0.0f && qK == 0.0f && qReal == 0.0f) return 0.0f;
  float yawRadians = atan2(2.0f * (qI * qJ + qReal * qK),
                           (qReal * qReal + qI * qI - qJ * qJ - qK * qK));
  return yawRadians * (180.0 / PI);
}

float readHeading() {
  float h = fmod(readYaw() - initialYawOffset + 540.0, 360.0) - 180.0;
  return IMU_YAW_SIGN * h;
}

void zeroYaw() {
  Serial.println(F("# zeroing yaw"));
  unsigned long t = millis();
  while (millis() - t < 3000) {
    if (myIMU.wasReset()) myIMU.enableGameRotationVector();
    if (myIMU.getSensorEvent() && myIMU.getSensorEventID() == SENSOR_REPORTID_GAME_ROTATION_VECTOR) {
      initialYawOffset = readYaw();
      Serial.print(F("# zero yaw ")); Serial.println(initialYawOffset);
      return;
    }
    delay(10);
  }
  Serial.println(F("# ERROR no IMU event to zero"));
}

// ---- colour ----
void readColor(uint16_t &r, uint16_t &g, uint16_t &b, uint16_t &c) {
  if (!tcsOk) { r = 0; g = 0; b = 0; c = 0; return; }
  tcaselect(TCS_CH);
  Wire.beginTransmission(0x29);
  Wire.write(0x80 | 0x20 | 0x14);      // command | auto-increment | CDATAL
  Wire.endTransmission();
  Wire.requestFrom((uint8_t)0x29, (uint8_t)8);
  if (Wire.available() < 8) { r = 0; g = 0; b = 0; c = 0; return; }
  c  = (uint16_t)Wire.read();  c |= (uint16_t)Wire.read() << 8;
  r  = (uint16_t)Wire.read();  r |= (uint16_t)Wire.read() << 8;
  g  = (uint16_t)Wire.read();  g |= (uint16_t)Wire.read() << 8;
  b  = (uint16_t)Wire.read();  b |= (uint16_t)Wire.read() << 8;
}

// Calibrated on the mat: white pR 47 / pB 19, orange pR 69 / pB 11,
// blue pR 36 / pB 27. Orange is tested first.
BlockColor classifyColor() {
  uint16_t r, g, b, c;
  readColor(r, g, b, c);
  float total = (float)r + (float)g + (float)b;
  if (total < 100.0f) return COLOR_NONE;
  float pR = (r / total) * 100.0f;
  float pB = (b / total) * 100.0f;
  if (pR > 52.0f && pB < 18.0f) return COLOR_ORANGE;
  if (pB > 23.0f && pR < 40.0f) return COLOR_BLUE;
  return COLOR_NONE;
}

const unsigned long COLOR_CONFIRM_MS = 6;
BlockColor    pendingColor = COLOR_NONE;
unsigned long pendingStart = 0;

void resetColorDetector() { pendingColor = COLOR_NONE; pendingStart = 0; }

// Colour mute. Backing away from a wall drags the sensor back over lines
// already used. Muting from the start of the reverse until the car is
// forward of that point again means those re-crossings are ignored.
// gRawColor is NOT muted, so the LEDs still show what is underneath.
bool colorMuted    = false;
long colorMuteFrom = 0;

BlockColor detectColor(BlockColor wantColor) {
  if (colorMuted) { resetColorDetector(); return COLOR_NONE; }
  BlockColor rawColor = gRawColor;
  if (wantColor != COLOR_NONE && rawColor != wantColor) rawColor = COLOR_NONE;

  if (rawColor == COLOR_NONE)   { resetColorDetector(); return COLOR_NONE; }
  if (rawColor != pendingColor) { pendingColor = rawColor; pendingStart = millis(); return COLOR_NONE; }
  if (millis() - pendingStart >= COLOR_CONFIRM_MS) { resetColorDetector(); return rawColor; }
  return COLOR_NONE;
}

// ---- called once at the top of every loop ----
void serviceSensors() {
  lidarNewFrame = false;
  serviceLidar();
  if (lidarNewFrame) { frontHist[frontHistIdx] = lidarF; frontHistIdx = (frontHistIdx + 1) % 5; }

  gImuFresh = false;
  if (myIMU.wasReset()) myIMU.enableGameRotationVector();
  if (myIMU.getSensorEvent() &&
      myIMU.getSensorEventID() == SENSOR_REPORTID_GAME_ROTATION_VECTOR) {
    gImuFresh = true;
    float h = readHeading();
    unsigned long now = millis();
    float dt = (now - gPrevHT) / 1000.0;
    if (dt > 0.0) gYawRate = wrapDeg(h - gPrevH) / dt;
    gPrevH = h; gPrevHT = now;
    gHeading = h;
  }

  gRawColor = classifyColor();
  if (currentState != STATE_FINISHED) {
    digitalWrite(LED2_PIN, gRawColor == COLOR_ORANGE ? HIGH : LOW);
    digitalWrite(LED3_PIN, gRawColor == COLOR_BLUE   ? HIGH : LOW);
  }
}
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
void loop() {
  serviceSensors();

  // ---- startup gate ----
  // Nothing below this runs until the Pi has sent at least one
  // well-formed frame (lidarFrames > 0). Before that, we just keep
  // draining Serial and slow-blink the onboard LED. The start button is
  // not read here, so it can't launch the car before the Pi is up.
  if (!fsmStarted) {
    if (lidarFrames == 0) {
      statusBlink(500);
      return;
    }
    fsmStarted = true;
    statusLed(true);
    Serial.println(F("# first LiDAR frame received - FSM starting"));
  }

  // ---- button: start (WAIT_START), pause / resume (running), restart (FINISHED) ----
  btnPress = startButtonPressed();
  if (btnPress) {
    if (currentState == STATE_PAUSED) {
      btnPress = false;
      resumeRun();
    } else if (currentState == STATE_FINISHED) {
      btnPress = false;
      Serial.println(F("# RESTART (button)"));
      startRun();
    } else if (currentState != STATE_WAIT_START) {
      btnPress = false;
      pauseRun();
    }                                // WAIT_START: waitStartStep() consumes it
  }

  // Release the colour mute once we are forward of where the reverse began.
  if (colorMuted && currentState != STATE_RECOVER && readEncoder() >= colorMuteFrom) {
    colorMuted = false;
    Serial.println(F("# colour re-enabled"));
  }

  // Wall panic overlay: interrupts any moving state and resumes it.
  // Disabled when the LiDAR is stale - there is no front distance to act on.
  if (!lidarStale &&
      currentState != STATE_RECOVER &&
      currentState != STATE_WAIT_START &&
      currentState != STATE_FINISHED &&
      currentState != STATE_PAUSED &&
      !driveTurnArmed() &&                 // a straight turns at the front fallback instead
      recoverTries < RECOVER_MAX_TRIES &&
      lidarF <= WALL_PANIC_MM) {
    enterRecovery();
  }

  // Onboard LED: solid while the Pi is feeding frames (ready or running),
  // fast blink if the feed goes stale. Always solid once FINISHED.
  if (currentState == STATE_FINISHED) statusLed(true);
  else if (currentState == STATE_PAUSED) statusBlink(250);
  else if (lidarStale)                statusBlink(100);
  else                                statusLed(true);

  switch (currentState) {
    case STATE_WAIT_START:      waitStartStep();     break;
    case STATE_DRIVE_TO_CORNER: driveStep();         break;
    case STATE_TURNING:         turningStep();       break;
    case STATE_FINAL_STRAIGHT:  finalStraightStep(); break;
    case STATE_RECOVER:         recoverStep();       break;
    case STATE_PAUSED:          setMotorSpeed(0);    break;   // until the next press

    case STATE_FINISHED:
      if (!entered) {
        entered = true;
        Serial.println(F("# FINISHED"));
        setMotorSpeed(0);
        setServoAngle(SERVO_TRUE_STRAIGHT);
        statusLed(true);
        digitalWrite(LED2_PIN, HIGH);
        digitalWrite(LED3_PIN, HIGH);
      }
      break;
  }
}

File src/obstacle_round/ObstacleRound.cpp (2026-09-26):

#include <Arduino.h>
#include <Servo.h>
#include <SPI.h>
#include <Wire.h>
#include <SparkFun_BNO08x_Arduino_Library.h>
#include <VL53L0X.h>                 // Pololu VL53L0X library (front + rear ToF)

#ifndef DEG_TO_RAD
#define DEG_TO_RAD 0.017453292519943295
#endif

// ============================================================
// OBSTACLE ROUND - NON-BLOCKING FIRMWARE  (v11.3; the parameter table is off)
//
// v11.3 vs v11.2 - park-in when a start-section sign keeps the car on the far
// side of the lane (CW: a red at the lot / CCW: a green), so the side beam
// never sees the blocks ("no lot found")
//   - memory lot: the lot never moves (rules), so the park-out memory, fixed
//     by the wall ahead (+-15 mm), places it when the beam found nothing
//     (PARK_MEMORY_LOT; PARK_MEMORY_ODO_OK = also from odometry alone). A lone
//     block that fits the memory is used first. The finder logs why it missed
//   - not handed over mid-swerve: at the stop point but yawed round a sign ->
//     on until straight (PARK_HANDOFF_YAW_DEG, at most PARK_HANDOFF_MAX_OVER_MM)
//   - SETTLE: STRAIGHTEN (one full-lock arc) when yawed; re-measures the lot
//     wall (cone + beam agree, not beside the lot); SIDESTEP / PASS plans are
//     checked pose by pose against the remembered signs (piSPathClear) and
//     the room ahead / behind; PASS can go BACK past a sign (no room ahead);
//     ADJUST / PASS stop for a sign on the car's own line
//   - the final straight remembers every sign seen in it (PARK_TRACK_KEEP_MM)
//
// v11.2 vs v11.1
//   - the car's real shape in the sign planner: LIDAR_TO_FRONT_MM ahead of the
//     LiDAR, the rest of PARK_CAR_LEN_MM (210) behind it. v9-v11.1 checked a
//     120 mm body centred on the LiDAR (CAR_HALF_LEN_MM 60), so the REACH
//     simulation never saw the car's back end: close calls on signs
//   - park-in MEASURE: with the LiDAR above the block ends (the car is longer
//     than the lot is deep, LiDAR near the front) the side beams are not used
//     and x comes from the swing's odometry - no more "side beam reads open"
//   - TURN_ALWAYS_ARC (off): inner-pass corners as forward arcs too (see there)
//
// v11.1 vs v11
//   - corners: every reverse stops at the rear ToF (TURN_REAR_STOP_MM 60); a
//     reverse arc stopped short finishes FORWARD (3-point); after a forward
//     finish - the wide PLAN_ARC turn - the car backs straight up on the new
//     heading until the rear ToF reads TURN_BACKUP_REAR_MM (60)
//   - BACKOFF and RECOVER reversing stop at the rear ToF too
//   - more air to the signs: PASS_MARGIN_MM 150 -> 200, REACH_SAFETY_MM 20 -> 35
//   - LOT_SIGN_REJECT: on the lot straight a RED/GREEN "sign" on the lot's half
//     of the lane is dropped (the rules put that straight's signs inside)
//   - park-in PIVOT: slower legs (PARK_IN_LEG_VMAX_MMPS), 5 stuck legs allowed
//
// v11 vs v10: PARK IN - after the 3 laps the car parks in the lot
//   (see "PARK IN" below for the whole sequence and its tunables)
//   - the final straight no longer stops after L - A: it finds the lot with
//     the lot-side LiDAR beam (two blocks LOT_LEN_MM apart), helped by the
//     park-out's memory of where the lot is (measured against the wall ahead)
//     and the camera's MAGENTA blocks (new frame fields 18-19)
//   - then: stop past it, one reverse full-lock swing to perpendicular, back
//     to the wall on the rear ToF, measure the blocks with the side beams,
//     the park-out's forward/back legs turn it parallel inside the lot
//     (a ceiling in the body model keeps it in), centre on the two ToFs
//   - PARK_IN_TEST = true: START parks at once (standalone test)
//   - FIRST_CORNER_MIN_RUN_MM (0 = off): no first corner this soon after GO
//   - the park-out legs got per-maneuver tolerance / margin (defaults as v10)
//   Laps are unchanged (host sim, park-in off: same pass / contact counts).
//
// v10 vs v9: PARK OUT merged in (from experimental/park_manuever.ino)
//   - START now begins in the parking lot: STATE_PARK_OUT pivots the car 90 deg
//     toward the open side with full-lock shuffles, drives out until the front
//     reads EXIT_FRONT_MM, reverse-arcs back to the lot heading, and only then
//     starts the laps - with the lane heading taken from the lot (the car was
//     parked parallel to the wall, so that heading IS the lane direction).
//     PARK_OUT_ENABLE = 0 starts the laps at once, as v9 did.
//   - two VL53L0X ToFs on the mux: FRONT CH3, REAR CH4 (CH4 was the floor
//     colour sensor, which is gone - it only ever drove LED2/LED3). LED2 / LED3
//     now light while the front / rear ToF is answering.
//   - park-out guards: front/rear ToF, a body model (encoder + IMU move the
//     car's outline past the two lot blocks and the wall - it guards the
//     corners the ToFs cannot see), speed-controlled legs with learned braking.
//     Front ToF down -> the LiDAR front stands in; rear ToF down -> every
//     reverse leg is capped at half a wheel turn.
//   - START is refused while the IMU gives no heading.
//   - TURN_OUTER_FRONT_MM 400 -> 600; the lot straight's lane is
//     START_LANE_MM (800) wide - the car keeps off the lot blocks every lap.
//   The obstacle driving itself (planner, corners, REACH, final straight) is
//   unchanged from v9.
//
// v9 vs v7
//   - one sign per frame (the largest blob); fields 15-17 are parsed past
//   - corner trigger: the side beam alone (no cone test); before the direction
//     is known the side with the LONGER beam is the candidate; an odometry
//     window (path since the last corner trigger) gates it:
//       < CORNER_MIN_RUN_MM (2000)       never a corner
//       > CORNER_FALLBACK_RUN_MM (2700)  relaxed evidence (1 rev, no wall history)
//   - more air to a sign (PASS_MARGIN_MM 150) and a yaw cap while alongside
//     one (ALONGSIDE_YAW_MAX), so the swept body corner cannot clip it
//   - reach check rebuilt: a forward simulation of the real steering loop,
//     judged against the car's swept outline, decided once per LiDAR rev in a
//     distance window, confirmed over REACH_CONFIRM revs (stopped); a BACKOFF
//     reverses a PLANNED distance in one go (see "REACH" below), never with
//     the rear corner at a wall
//   - the planner looks at ONE sign ahead only - the nearest - never at the
//     one after it; PASS_HOLD_MM 250 -> 30
//   - a PLAN_REVERSE corner approaches on the inner half (TURN_REV_INNER_MM):
//     the reverse arc swings the car toward the old lane's outer wall
//   All of it was run against a host simulation of the field (the real .ino
//   compiled for the PC, 100 random sign layouts x 2 seat patterns).
//
// The STM32 owns all driving. The Pi (obstacleRound.py) is a sensor pipe:
// LiDAR + camera in, one CSV line out at up to 50 Hz, plus START/STOP and
// tuning lines on the same port. Nothing here blocks after setup().
//
// SERIAL FRAME (Pi -> STM32), 20 comma-separated integers (18 still parse):
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

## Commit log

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2026-07-12 Add steering-mechanism study (kinematic + pymunk dynamic); confirm single central pivot for parking
2026-07-13 Lock v1 geometry (track120/WB128/wheel40); add layout optimizer + car blueprint; day-01 journal
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2026-07-26 Supersede design decisions with as-built: parallelogram steering, VL53L0X, TCS turn trigger
    Dated SUPERSEDED blocks on #1/#4/#7; #14 confirmed with 5:1 ratio; adds #15-22. Original reasoning preserved.
2026-07-26 SPECSHEET as-built: track 105, lock 35deg, 5:1 reduction, section 11 electrical
    Corrects odometry: 0.175 mm/count at 900 counts/rev on a 50mm rear wheel.
2026-07-26 BOM rewrite against as-built parts; flag Sharp fallback lead time as unrecorded
2026-07-26 Add electrical architecture, collimator solver and wiring block diagram
    I2C buses split: VL53L0X and TCS34725 both ship at 0x29. Collimator snout plus 2deg wedge moves floor first-return from 166mm to 870mm.
2026-07-26 Add park feasibility solver: symmetric two-arc infeasible at 35deg lock
    Front-outer corner strikes the entry limitation by 25.6mm. Scale-invariant. Strategy changed to multi-point shuffle closed on IMU yaw.
2026-07-29 Decisions 23-28: PCA9548A mux replaces XSHUT addressing; IMU split; 40deg lock
    Mux gives one sensor per channel so every device keeps factory 0x29. Kills the volatile-address-on-brownout problem and the 2.8V XSHUT hazard, and returns five GPIO. Cost on the record: mux is a single point of failure and the TCS loses the private bus that isolated it from ToF cable faults, so MUX_RST is wired to the MCU.
    MPU9250 is not on hand. MPU6050 (I2C-only, WHO_AM_I 0x68) goes on mux ch7 for bench work only; an SPI part races. Competition IMU not yet ordered - longest lead item left.
    Lock 35->40deg pulls R into the 120-150mm band, but park_feasibility still shows -10.8mm at 40deg, so the multi-point shuf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
2026-07-29 Electrical revision for two-board single-sided build; add fab rules and geometry sweep
    Fab does double-sided without plated through-holes, so two-layer is unusable and there is no ground plane at any layer count. At 0.5mm minimum trace and space no trace fits between adjacent header pins (0.54mm available, 1.8mm needed), so placement rather than routing is the design problem. Split into Board A (MCU, drive, power) over Board B (mux, sensors), 40mm 6-pin link.
    Pin map corrections: drive PWM moved off PA0/PA1 to PB8/PB9 - PA0 is the Black Pill KEY button, so driving it push-pull shorts an output to ground when pressed. SPI1 on PB3/PB4 needs JTAG released and SWD kept or it silently fails. PB5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
2026-07-29 Expand README into a full build record
    Adds the electronics section, the four findings that changed the design, and the reproduce-the-analysis commands. Keeps the rule citations, event lockout and first-pair direction decode. Notes explic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
2026-07-30 Add pin-level STM32 wiring diagram; document BNO08x strapping and Pi UART setup
    schemes/stm32_wiring.svg shows every allocated pin, its peripheral and what it connects to, colour-coded by bus. schemes/README.md indexes both diagrams and notes the SVG is hand-maintained alongside the pin map.
    BNO08x breakout: the purple CJMCU board labels its pads with I2C names and three change meaning in SPI mode - SCL is SCK, SDA is MOSI, AD0 is MISO. Nothing on the silkscreen says so. PS1 and PS0 both strap HIGH to select SPI; left floating the part comes up in an undefined protocol and looks completely dead. Strap them on the module so the harness stays at 8 wires. IMU harness corrected 7-pin to 8-pin -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
2026-07-30 Wheelbase measured at 110 mm; withdraw Decision 28, lock stays 35 deg final
    Wheelbase is 110 mm, front axle centre to rear axle centre, measured 2026-07-28. Ceiling was 117 mm from the 165 mm body length. This closes the last geometry unknown and confirms the numbers park_feasibility was already run against.
    R = 110 / tan 35 = 157 mm, R/L = 0.95, rake = atan(2/110) = 1.04 deg (previously quoted as a 1.0-1.1 deg range while the wheelbase was unknown).
    Decision 28 withdrawn the same day it was made. Raising the lock to 40 deg would have put R at 131 mm and inside the 120-150 mm target band, but that band is a guideline from the July 12 optimiser, not a rule limit, and 40 deg still fails the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
2026-08-07 Add TCS34785 color sensor tester
    This file tests the TCS34725 color sensor using the TCA9548A multiplexer. It initializes the sensor and reads color data from multiple channels.
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2026-08-19 obstacle plan 2 with cooldown after obstacle avoidance
    [obs2.cpp]
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2026-09-05 feat(hardware): upgrade SBC to Raspberry Pi 5 (8GB), integrate RPLIDAR C1 and 160° FOV camera
2026-09-11 docs: full build documentation, calibration suite, and Pi perception stack
    Restructure the repository so somebody who has never seen this car can build
    one, calibrate it, and understand why it drives the way it does.
    Documentation (new docs/ folder)
    - LOGIC.md: the whole control logic in plain language - the two-tier
    architecture and why the Pi can only advise, direction locking, the
    heading-terminated turn law, the lane-gap lateral correction, the six-phase
    pillar avoidance with its recovery path, and the Pi threading model
    - CALIBRATION.md: all eight calibration steps written for someone who has
    never done them - the rig, the procedure, the expected numbers, and how to
    tell a ba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
    [01_encoder_ticks_per_rev.cpp, 02_ticks_per_cm.cpp, 03_steering_jerk.cpp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]
2026-09-11 docs: fold everything into one sectioned README, add diagrams, clean the tree
    The repository now has a single entry point. Everything a reader needs is in
    README.md, numbered 1 to 15 with a contents table, and every section ends with
    a link back to it.
    Documentation
    - Merge the five docs/ pages into README.md as sections 5, 7, 8, 10 and 11
    (how the car thinks, build from scratch, calibration, engineering log,
    troubleshooting) and remove docs/
    - Add a contents table and a "looking for one specific thing" index that maps
    a question to the exact section or file that answers it
    - Back-to-top link at the end of every section
    Diagrams
    - media/diagrams/lane-gap-correction.svg: the radial co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
    [obs2.cpp]
2026-09-11 docs: steering is now true Ackermann; parallelogram scrubbed
    Third steering geometry. The parallelogram fixed the swept-envelope problem the
    centre pivot had, but drove both front wheels to the same angle. In a turn the
    inner wheel is on a tighter radius and needs more angle, and that difference
    came out as scrub.
    Observed on the car: audible squeal and scuffing through corners, wide corner
    exits, and the same commanded steering angle producing a different heading
    change from run to run.
    The second-order effect is the one that mattered. A scrubbing tyre rotates
    further than the car travels, so the encoder over-reads - and the lane-gap
    lateral correction is pure odometry. The steering geome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
2026-09-11 docs: a figure for every calibration step
    Eight plots, one per calibration step, embedded in section 8. Each one shows
    what a correct result looks like next to what a broken one looks like, so the
    reader knows what they are looking at before they have their own data.
    - 01 encoder ticks: tight single peak versus the bimodal distribution a
    slipping coupler produces
    - 02 ticks per cm: the least-squares fit with a residual panel, and what a
    pattern in the residuals means
    - 03 steering jerk: the jerk spike with and without slew limiting, plus peak
    jerk against slew limit with the knee marked
    - 04 true straight servo: the V curve, and what a flat or edge-shifted curve
    tells you
    - 05 ToF t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
2026-09-11 docs: illustrate every component on the car
    A twelve-panel figure in section 3, one card per component, colour-coded by
    subsystem: real-time control, power and motion, sensing, perception. Each card
    carries the part, its headline spec, the job it does on this car, and the one
    thing worth knowing about how it is wired or why it was chosen.
    These are drawn, not sourced. Vendor product photographs are copyrighted and
    this repository is public, MIT licensed, and something WRO reserves the right
    to republish - so shipping scraped product shots would put a licensing problem
    into the repo. Original illustrations avoid that entirely and match the rest of
    the figures.
    media/diagrams/_generate_compo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
2026-09-11 fix(readme): blank lines around HTML blocks so tables render
    The specification table in section 3 was rendering as one run-on paragraph.
    Cause: the component figure was inserted with its closing </p> pressed
    directly against the table header, and GitHub's Markdown needs a blank line
    between an HTML block and the block that follows it - without one, the table
    is swallowed into the HTML block and the pipes render as literal text.
    Same fault existed after all eight calibration figures and the achievements
    caption; those followed prose rather than tables so the damage was less
    obvious, but the paragraph after each figure was being absorbed too.
    Ten blank lines inserted. Verified by rendering t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
2026-09-15 Add sensor check and color threshold calibration sketch
    This file implements a standalone Arduino sketch for sensor check and color threshold calibration using ToF and color sensors.
2026-09-15 Create tof_color_sensor_routine.txt with calibration details
    Added instructions for TOF color sensor calibration and usage.
2026-09-16 Refactor comments and adjust motor/color logic
    Updated comments for clarity and accuracy, modified motor control logic and color classification function.
2026-09-18 Refactor ToF sensor test code structure
    Refactor the ToF sensor test code to improve structure and readability. Update sensor initialization and data handling for better clarity and maintainability.
2026-09-18 docs: fix README faults and reconcile docs with firmware
    - Fix broken anchors/links (badge, Pi/tools READMEs, DECISIONS line links, video paths)
    - Reconcile constants, sensors, pin maps with OpenRound.cpp and ObstacleRound.cpp
    - Correct state machine, corner-priority, lane-gap and avoidance descriptions
    - Replace non-existent PlatformIO build with Arduino/STM32duino steps
    - Fix Pi dashboard port (8080), camera resolution, unimplemented UART sender
    - Replace pip-freeze requirements.txt with actual dependencies
    - Mark missing WRO deliverables (photos, CAD) and stale schematic honestly
    - Flag open issues: start button not read (rule 9.11), signal filter direction,
    wheelbase vs body length, ob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
2026-09-18 simple tof read standalone sketch with mux reset
    [tof_test.ino]
2026-09-19 Add obstacle round STM32 executor firmware
    Moves the obstacle round to a Pi-owned state machine. The Pi runs perception +
    strategy and emits DriveCommands; the STM32 executes them and reports back.
    The open round is unchanged — OpenRound.cpp still owns it end to end with the
    Pi electrically absent. ObstacleRound.cpp is left intact as a fallback.
    Command interface (the load-bearing decision):
    - speed crosses the wire as mm/s, closed-loop on the encoder (Decision #22)
    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
2026-09-19 Lane correction is removed entirely, including the state, constants, gate carry-over, and recovery case. After the turn arc, the car goes straight back to DRIVE on the new heading, held by the IMU. T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
    [OpenRound.cpp]
2026-09-19 feat(models): add Front Bumper STEP assembly and 3D printable STL files
    [Center BR.stl, Front Bumper v45.stl, Front Bumper.stl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]
2026-09-19 feat(models): add wheel hubs, motor mounts, and chassis connectors STLs
    [Connector B22.stl, Left Front Wheel.stl, Left Rare Wheel New.stl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]
2026-09-19 feat(models): add baseplate, middle deck, LiDAR mount, and rear ToF bracket STLs
    [Back TOF.stl, Base Plate.stl, LEGO Shaft.stl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]
2026-09-19 feat(models): add Tail rear wing spoiler STL model
    [Tail .stl]
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2026-09-19 Refactor OpenRound logic and improve comments
    Updated comments for clarity, adjusted servo constants, and refined turn logic to improve direction locking and color detection.
2026-09-19 Add ObstacleLap.cpp: obstacle round firmware, lap only
    Fork of OpenRound.cpp with one state added (AVOID) and the ASCII
    lidar-only link replaced by the binary PERCEPT/TELEM protocol shared
    with BlueprintPi. Everything already calibrated for the open round —
    servo trim/limits, TICKS_PER_CM, the heading PID, the eased 90 deg
    arc, colour thresholds, wall recovery — is unchanged and still runs
    the car.
    States: BOOT -> HEADING -> AVOID -> TURN90 -> FINISH, with RECOVER
    as an overlay. Corner trigger now debounces on lidar revolutions
    (not frames) and is locked out after an avoid leg. Finish is
    detected by matching front-wall distance to the start, with the
    open round's odometry L-A calculatio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
2026-09-20 dashboard on-off function and lidar based tof for ctrl instead of colour sensor
2026-09-20 obstacle: preserve corner progress across an avoid, shrink post-avoid lockout
    - headingStep(): only zero the side open-revolution counters on a fresh
    GO or a finished turn, not when re-entering from AVOID
    (suppressCornerReset) — a pillar sitting right before a corner no
    longer costs the corner.
    - avoidStep(): leg/cap/timeout are now a last-resort backstop only, for
    a genuinely stuck link — normal release is entirely the Pi's
    AVOID_NONE, matching supervisor.py's new no-leg model.
    - POST_AVOID_LOCKOUT_CM: 30 -> 15 cm, since it now only needs to cover
    PID settle time, not a leg that no longer exists. Re-tune on the mat.
2026-09-20 Revert "avoid: drop COMMIT lifecycle" — back to the leg-driven avoid
    Restores the IDLE -> TRACK -> COMMIT -> IDLE supervisor: COMMIT freezes the
    solve and runs the leg out on odometry, carrying the car past a pillar the
    camera can no longer see.
    - control/supervisor.py, tests/test_supervisor.py: restored verbatim
    (_freeze/_run_commit/COMMIT_TIMEOUT_S, leg countdown, commit_* snapshot).
    - obstacle_lap.py: AVOID_COMMIT import, the committed-leg send exception,
    CMIT in _aname.
    - dashboard.py: commit_left_mm/commit_age_s/leg_mm back in the run status.
    - templates/index.html: COMMIT chip, supPhase/renderSup COMMIT branches,
    AVOID Leg row, leg complete/timed out notes, AVOID_LOCK 150 -> 3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
2026-09-20 fixed faar case
2026-09-20 Move obstacle-round FSM and lane planner from STM32 to the Pi
    The old repo carried two half-finished generations of obstacle-round
    code and a firmware-side FSM with no working Pi-side driving logic.
    This replaces both with a single architecture: the Pi owns the FSM,
    lane planner, corner logic and pillar/wall perception; the STM32 keeps
    only the fast control loops (heading PID, arc servo, panic reflex,
    odometry/IMU/colour sensing, motor/servo PWM) and a matching 20-entry
    parameter table. A new binary DRIVE/TELEM frame replaces the old
    ASCII and PERCEPT protocols on the link.
    - control/fsm.py, planner.py, mapper.py, link.py, intent.py: new
    Pi-side FSM, lane planner, and wire protocol
    - firm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
    [ObstacleRound.cpp]
2026-09-20 firmware: fix .ino build - classifyColor no longer returns a sketch-local type
    The Arduino IDE builds a .ino by inserting auto-generated prototypes above
    everything but the #includes, so `BlockColor classifyColor()` was declared
    before `enum BlockColor` existed: "'BlockColor' does not name a type".
    classifyColor() and gRawColor are now uint8_t, which is what TELEM carries
    anyway; the enum stays as named constants with an explicit uint8_t base.
    No behaviour change.
    [ObstacleRound.cpp]
2026-09-21 feat(models): add ASMB.step CAD master, ASMB.stl for native GitHub 3D viewing, and web viewer
    [ASMB.stl]
2026-09-21 docs: add 3D CAD digital twin 360 animation and GitHub 3D viewer links
2026-09-21 update: sync updated ASMB.step, recompile ASMB.stl (v45), and refresh 3D digital twin
    [ASMB.stl]
2026-09-21 feat(models): integrate master ASMB.3mf (1028 parts), recompile ASMB.stl (764k tris), and update 360 CAD animation
    [ASMB.3mf]
2026-09-21 docs: replace hardware architecture banner with real component BOM table, international/local links, and pricing
2026-09-21 Port the second-pillar corner logic and fixes from the updated firmware
    The updated obstacle-round firmware decides which side to leave each corner
    on from the SECOND-largest pillar in frame - usually the first pillar of the
    next straight - and shapes the arc to match. All of that is planner logic,
    which lives on the Pi in this repo, so it is ported to Python; the executor
    firmware's code is unchanged.
    Planner / FSM
    - camera reports the next-largest accepted blob as Detection.second; the
    run loop locates it with the LiDAR like any other sighting
    - LanePlanner.track_secondary(): believe its colour only when it lands
    outside this corridor, toward the turn, and further than the pillar bein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
    [ObstacleRound.cpp]
2026-09-21 docs: update vehicle dimensions across repo to verified CAD measurements and track new printable STLs
    [Camera Holder ras.stl, Stearing Holder .stl, Top Plate.stl]
2026-09-21 docs: add 3D printing sponsor section for rapidPCB with official logo and Facebook link
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2026-09-24 Refactor button handling and state management
    Refactor button handling and state management for improved clarity and functionality. Update comments for better understanding of the code logic.
2026-09-24 Refactor ToF test for dual sensor support
    Updated ToF test code to support both front and rear sensors with non-blocking reads and improved statistics tracking.
2026-09-24 Refactor ToF sensor reading and initialization
    Refactor ToF sensor reading code for clarity and efficiency. Consolidate initialization and reading logic for front and rear sensors.
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2026-09-24 Improve IMU initialization and diagnostics
    Enhanced IMU initialization with detailed diagnostics and error handling.
    [park_manuever.ino]
